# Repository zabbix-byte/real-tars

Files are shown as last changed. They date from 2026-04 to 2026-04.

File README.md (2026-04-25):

# TARS Project — Real Robot

> Inspired by TARS from *Interstellar*.
> A rectangular articulated monolith that hears, thinks, speaks, sees, **walks**, learns and insults you. Real autonomous embodied agent in a 23 cm chassis.

> **Status (April 2026):** architecture v2 — split brain (Radxa Zero 2 Pro) + body (XIAO ESP32-S3) + cloud agent (Pipecat + Gemini Live, free tier).

---

## Architecture v2 — Three layers

The project now follows the canonical robotics pattern: high-level cognition, mid-level perception, and low-level motor control are physically separated.

```mermaid
graph TB
    subgraph CLOUD["LAYER 3 - COGNITION (cloud, free tier)"]
        GEM["Gemini 2.0 Flash Live - WebSocket streaming voice + vision"]
        MEM["OpenClaw memory (local SQLite, no SaaS)"]
    end

    subgraph BRAIN["LAYER 2 - AGENT (Radxa Zero 2 Pro inside chassis)"]
        PIPE["Pipecat pipeline - LLM streaming, tool calling, barge-in"]
        OPENCLAW["OpenClaw skills - WhatsApp/Telegram, persistent memory, browser"]
        FALLBACK["Local fallback: Qwen 2.5 7B + Whisper + Piper on NPU 5 TOPS"]
        TOOLS["Tool registry: walk(), look(), say(), remember(), recall(), check_safety()"]
    end

    subgraph BODY["LAYER 1 - HARDWARE DAEMON (XIAO ESP32-S3 Sense)"]
        CAM["OV2640 camera - MJPEG stream HTTP local"]
        MIC["PDM mic - PCM stream"]
        SPK["I2S speaker MAX98357A"]
        SERVOS["2x Corona DS-538MG servos - WALK gait state machine"]
        TOF["3x VL53L1X (front 4m + 2 lateral 45deg) + VL53L0X cliff"]
        IMU["MPU6050 - tilt, fall detection"]
        OLED["OLED 2.42 inch SSD1309 - face"]
    end

    PIPE -->|WebSocket| GEM
    PIPE --> TOOLS
    OPENCLAW --> MEM
    OPENCLAW --> TOOLS
    TOOLS -->|UART + HTTP local| BODY
    CAM -->|MJPEG HTTP| PIPE
    MIC -->|PCM WS| PIPE
    PIPE -->|TTS PCM| SPK
```

**Why this works:**

- **XIAO** does what an MCU does well: real-time sensor I/O, servo PWM, audio I²S, camera capture. It no longer talks to LLMs directly.
- **Radxa Zero 2 Pro** runs the agent loop, holds persistent memory, and orchestrates tool calls. Same physical footprint as a Pi Zero (65 × 30 × 5 mm) but with **NPU 5 TOPS** + 8 GB RAM. Fits inside the central block.
- **Cloud (Gemini Live)** is used only for the heavy multimodal streaming. **Free tier covers domestic use** (~3-4 h/day).

---

## Build Phases

| Phase | Name | Components | Result | Doc |
|---|---|---|---|-----|
| 1 | **Brain (legacy)** | XIAO + Groq + Telegram | Standalone mode: ESP32 talks to Groq via WiFi | [PHASE1_BRAIN.md](PHASE1_BRAIN.md) |
| 2 | **Senses** | 3x VL53L1X + 1x VL53L0X cliff + MPU6050 + speaker | Hears, speaks, measures, detects falls and edges | [PHASE2_SENSES.md](PHASE2_SENSES.md) |
| 3 | **Muscles** | LiPo + MT3608 + 2x Corona DS-538MG + OLED | Portable, with strong servos for actual walking | [PHASE3_MUSCLES.md](PHASE3_MUSCLES.md) |
| 3b | **Mechanics** | Chassis ABS 234x156x39 mm (Bambu X2D) | TARS-canonical body, no screws, snap-fit | [PHASE3_MECHANICS.md](PHASE3_MECHANICS.md) |
| 4 | **Monolith** | Full assembly + Radxa integration | Robot powers up, all hardware online | [PHASE4_MONOLITH.md](PHASE4_MONOLITH.md) |
| 5 | **Cognition** | Radxa Zero 2 Pro + Pipecat + OpenClaw + Gemini Live | True streaming agent: sees in real time, learns, remembers | [PHASE5_COGNITION.md](PHASE5_COGNITION.md) |
| 6 | **Locomotion** | Gait firmware + IMU loop + cliff guard | Walks forward/backward, turns, refuses stairs | [PHASE6_LOCOMOTION.md](PHASE6_LOCOMOTION.md) |

```mermaid
graph LR
    P1["P1: Brain (legacy)"] --> P2["P2: Senses"]
    P2 --> P3["P3: Muscles"]
    P3 --> P4["P4: Monolith"]
    P4 --> P5["P5: Cognition"]
    P5 --> P6["P6: Locomotion"]
```

---

## Component List

| # | Component | Price | Phase | Notes |
|---|---|---|---|---|
| 1 | XIAO ESP32-S3 Sense | EUR 14.00 | 1 | Hardware daemon, no longer the brain |
| 2 | Soldering kit 24-in-1 + multimeter | EUR 24.69 | 1 | One-off |
| 3 | VL53L1X ToF (0-4m) x3 | EUR 35.97 | 2 | 1 frontal + 2 lateral 45° |
| 4 | VL53L0X ToF (anti-cliff, downward) | EUR 5.00 | 2 | Stops robot at edges/stairs |
| 5 | MPU6050 IMU | EUR 2.00 | 2 | Fall detection, tilt feedback |
| 6 | MAX98357A I²S DAC | EUR 9.99 | 2 | |
| 7 | Speaker 3W 8Ω 40mm | EUR 8.99 | 2 | |
| 8 | **Corona DS-538MG digital servo x2** | **EUR 24.00** | 3 | **4.5 kg·cm — required for walking** |
| 9 | MT3608 DC-DC Boost (3.7→5V) | EUR 7.99 | 3 | Plus 1000 µF cap on servo line |
| 10 | Capacitor 1000 µF + silicone wire | EUR 4.00 | 3 | Servo current spike absorption |
| 11 | HXJN LiPo 3.7V 4200mAh BMS | EUR 22.99 | 3 | |
| 12 | Waveshare OLED 2.42" 128x64 SSD1309 | EUR 21.99 | 3 | |
| 13 | ABS filament (~220 g, full chassis) | EUR ~5.00 | 3b | Lighter than PETG, ~18% mass saving |
| 14 | **Radxa Zero 2 Pro 8 GB + 32 GB eMMC** | **EUR 55.00** | 5 | **Agent compute, fits inside central block** |
| 15 | USB-TTL cable for Radxa first flash | EUR 5.00 | 5 | |
| 16 | Miuzei starter kit (jumpers, breadboard) | EUR 10.99 | 1-3 | |
| | **TOTAL hardware** | **~EUR 257** | | |

### Cloud Services (free tier suffices for domestic use)

| Service | Cost | Function |
|---|---|---|
| **Gemini 2.0 Flash Live** | **EUR 0/month** (free tier ~4M tokens/day) | STT + LLM + TTS + vision streaming |
| OpenClaw (local) | Free | Agent skills, persistent memory, multi-app chat |
| Pipecat (local) | Free, open source | Streaming pipeline orchestration |
| Telegram Bot (optional, fallback) | Free | Out-of-house messaging |
| **TOTAL monthly** | **~EUR 0** | (worst-case ~5€/mo if free tier exceeded) |

> **Migration from v1**: Mem0 SaaS, OpenAI TTS-1 and Groq are no longer required. Their roles are absorbed by Gemini Live (multimodal) + OpenClaw (local memory). Saves ~€22/month vs the v1 stack.

---

## Cost Per Phase

| Phase | Hardware | Cumulative |
|---|---|---|
| Phase 1 - Brain | ~EUR 39 | ~EUR 39 |
| Phase 2 - Senses | ~EUR 62 | ~EUR 101 |
| Phase 3 - Muscles + Mechanics | ~EUR 86 | ~EUR 187 |
| Phase 4 - Monolith (assembly only) | EUR 0 | ~EUR 187 |
| **Phase 5 - Cognition (Radxa)** | **~EUR 60** | **~EUR 247** |
| **Phase 6 - Locomotion (extras)** | **~EUR 10** | **~EUR 257** |

---

## Interaction Flow (v2 — streaming)

```mermaid
sequenceDiagram
    actor User
    participant XIAO as XIAO (body)
    participant RADXA as Radxa (agent)
    participant GEM as Gemini Live (cloud)

    User->>XIAO: Speaks
    XIAO->>RADXA: PCM audio + MJPEG video (continuous, WiFi local)
    RADXA->>GEM: WebSocket stream (audio + video frames @ 2 fps)
    GEM-->>RADXA: TTS audio + tool_call("walk", "forward", 3)
    RADXA->>XIAO: UART command "WALK FW 3"
    XIAO->>XIAO: gait state machine moves servos
    RADXA->>XIAO: TTS PCM out
    XIAO->>User: Speaker plays voice
    RADXA->>RADXA: OpenClaw stores episode in local SQLite
```

---

## Final Specifications

| Spec | Value |
|---|---|
| Height | 23.4 cm (6 units of 39 mm, canonical TARS proportion) |
| Width | 15.6 cm (2 lateral arms 39 + central 78) |
| Depth | 3.9 cm |
| Weight | ~370 g (ABS chassis, no screws) |
| **Body MCU** | **XIAO ESP32-S3 Sense** (240 MHz, 8 MB PSRAM) — sensors, servos, audio I/O |
| **Agent compute** | **Radxa Zero 2 Pro** (6-core ARM @ 2.2 GHz, NPU 5 TOPS, 8 GB RAM) |
| **Cloud LLM** | **Gemini 2.0 Flash Live** via Pipecat (WebSocket streaming voice + vision) |
| **Local fallback** | Qwen 2.5 7B Q4 + Whisper small + Piper TTS on Radxa NPU |
| Memory | OpenClaw local SQLite (episodic + semantic) |
| Sensors | OV2640 camera, PDM mic, 3x VL53L1X (4m), VL53L0X cliff, MPU6050 IMU |
| Display | Waveshare OLED 2.42" 128x64 SSD1309 |
| Audio | MAX98357A + 3W 8Ω 40mm speaker |
| **Movement** | **2x Corona DS-538MG (4.5 kg·cm)** — supports actual walking gait |
| **Locomotion** | TARS-style alternating arm gait (lateral oscillation ±60°) |
| Battery | HXJN LiPo 3.7V 4200mAh + BMS (~3 h with Radxa active, ~6 h idle) |
| Power | MT3608 boost 3.7→5V + 1000 µF servo line cap |
| Safety | Anti-cliff (downward ToF), fall detection (IMU), prompt geofencing |
| Connectivity | WiFi 2.4 GHz, BT 5.0, Telegram, WhatsApp (via OpenClaw) |
| Languages | Spanish + Romanian (English emergent) |
| Humor | 0-100% (default 75%) |
| Body material | **ABS** (~220 g full chassis) on Bambu X2D |
| Chassis fit | All electronics inside central 78×33×~228 mm void, no screws |

---

## Quick Start

1. **Phases 1-4** build the body and prove that hardware works.
2. **Phase 5** drops the Radxa Zero 2 Pro into the central block, flashes Pipecat + OpenClaw, connects to Gemini Live.
3. **Phase 6** flashes the gait firmware on the XIAO and calibrates servos.

After Phase 6, TARS:
- Listens, sees, and answers in real time (latency <1 s).
- Remembers people and places across reboots.
- Walks forward, backward, turns left/right under voice command.
- Refuses stairs and edges via cliff sensor + agent safety prompt.
- Talks to you over WhatsApp/Telegram when you're not at home.

---

## Translations (legacy)

- [Documentacion en Espanol](TARS_Robot_Build_ES.md) — v1 architecture
- [Documentation en Francais](TARS_Robot_Build_FR.md) — v1 architecture

---

> *"Humor setting: 75%. Adjust upward at your own risk."* — TARS

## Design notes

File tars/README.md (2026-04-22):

# TARS · Phase 1 - Arduino IDE version

Sketch de Arduino IDE para **XIAO ESP32-S3 Sense**.

> Si prefieres PlatformIO (mejor para proyectos grandes), usa la carpeta [`../phase1_firmware`](../phase1_firmware).

---

## 1. Preparar Arduino IDE (una sola vez)

### a) Instalar soporte ESP32
1. Abre Arduino IDE.
2. `File → Preferences → Additional Board Manager URLs`, pega:
   ```
   https://raw.githubusercontent.com/espressif/arduino-esp32/gh-pages/package_esp32_index.json
   ```
3. `Tools → Board → Boards Manager` → busca **esp32** → instala **"esp32 by Espressif Systems"** (versión ≥ 3.0.0).

### b) Instalar librería
1. `Sketch → Include Library → Manage Libraries`.
2. Busca **ArduinoJson** (by Benoit Blanchon) → Install.

### c) Seleccionar la placa
`Tools → Board → ESP32 Arduino → XIAO_ESP32S3`

Y en el menú `Tools` ajusta:

| Opción | Valor |
|---|---|
| **USB CDC On Boot** | `Enabled` |
| **USB Mode** | `Hardware CDC and JTAG` |
| **PSRAM** | `OPI PSRAM` |
| **Flash Size** | `8MB` |
| **Partition Scheme** | `Huge APP (3MB No OTA/1MB SPIFFS)` |
| **Upload Speed** | `921600` |

---

## 2. Configurar el sketch

1. Copia `config.h.example` → `config.h` (en la misma carpeta).
2. Abre `config.h` y pon tus claves reales:
   - WiFi SSID + password (¡2.4 GHz!).
   - `GROQ_API_KEY` desde https://console.groq.com
   - `WHATSAPP_PHONE` y `CALLMEBOT_KEY` (ver README principal para activar CallMeBot).

---

## 3. Flashear

1. Conecta el XIAO por USB-C.
2. `Tools → Port` → selecciona el COM del XIAO.
3. Abre `tars_phase1.ino` (Arduino IDE cargará también los `.h` y `.cpp` automáticamente, los verás como pestañas arriba).
4. Pulsa **Upload** (→).
5. Abre **Serial Monitor** a `115200` baud.

> Si falla el upload: mantén pulsado **BOOT** mientras enchufas el USB, luego suelta y vuelve a darle Upload.

---

## 4. Uso

Habla cerca del XIAO. Cuando dejes de hablar ~1 s, TARS procesa y te manda la respuesta sarcástica por WhatsApp.

Salida típica del monitor serie:

```
===============================================
   TARS - Phase 1 Brain
===============================================
  Humor level: 75%
  STT model  : whisper-large-v3-turbo
  LLM model  : llama-3.1-8b-instant
===============================================
Connecting to WiFi: mi_red
......
WiFi OK, IP=192.168.1.42, RSSI=-58
Audio ready: 80000 samples, 160000 bytes PSRAM
TARS online. Speak to me. Or don't. I'm a robot.
Listening for wake sound...
Voice detected (amp=2840)
Recording...
Recorded 42300 samples (84644 bytes WAV)
[STT] -> Hola TARS, que tal estas?
[USER ] Hola TARS, que tal estas?
[LLM] -> Funcional. Lo cual es mas de lo que puedo decir de ti.
[TARS ] Funcional. Lo cual es mas de lo que puedo decir de ti.
[WA] WhatsApp sent OK
---------- ready for next input ----------
```

---

## 5. Archivos de este sketch

```
tars_phase1/
├── tars_phase1.ino         ← abrelo con Arduino IDE
├── config.h.example        ← copia a config.h
├── wifi_manager.{h,cpp}
├── audio_recorder.{h,cpp}  ← PDM I2S (GPIO 41/42)
├── groq_client.{h,cpp}     ← Whisper + Llama
└── whatsapp_client.{h,cpp} ← CallMeBot
```

Arduino IDE muestra todos estos archivos como **pestañas** en la parte superior del editor.

---

## 6. Problemas comunes

| Síntoma | Solución |
|---|---|
| `fatal error: ESP_I2S.h: No such file` | Actualiza el core ESP32 a ≥ 3.0.0 (`ESP_I2S.h` solo existe en 3.x). |
| `PSRAM not detected` | `Tools → PSRAM: OPI PSRAM` |
| Sketch demasiado grande | `Tools → Partition Scheme: Huge APP` |
| No detecta el COM | Pulsa BOOT + RESET, o instala el driver CP210x |
| WiFi no conecta | Comprueba que es **2.4 GHz** (ESP32 no soporta 5 GHz) |

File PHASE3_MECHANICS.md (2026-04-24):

# TARS — Mecánica Fase 3

> Diseño mecánico del chasis impreso para **Bambu Lab X1 / P1S** en PETG.  
> Proporciones canónicas TARS (9 u alto · 4 u ancho · 1 u fondo) respetando todos los componentes reales adquiridos.

---

## � Aspecto del robot (vista frontal a escala)

```
       ┌───┐ ┌───────┐ ┌───┐          ── 351 mm
       │   │ │░░░░░░░│ │   │   ← OLED 2.42" (z 295–340)
       │   │ │░░░░░░░│ │   │
       │   │ ├───────┤ │   │
       │   │ │  ▓▓▓  │ │   │   ← Servos A/B (z 225–295)
       │   │ │  ▓▓▓  │ │   │
       │   │ │ •   • │ │   │   ← ToF VL53L1X (z 200–225)
       │   │ │   ◉   │ │   │   ← Cámara OV2640 (z 170–200)
       │   │ │ ╱╲╱╲╱ │ │   │   ← Rejilla altavoz ø40 (z 125–170)
       │   │ │ ═════ │ │   │   ← MT3608 + switch (z 110–125)
       │   │ │▓▓▓▓▓▓▓│ │   │
       │   │ │▓ BAT ▓│ │   │   ← Batería HXJN 4200 mAh
       │   │ │▓▓▓▓▓▓▓│ │   │     (z 10–100, 90 mm alto)
       │   │ │▓▓▓▓▓▓▓│ │   │
       │ ▪ │ │   ▪   │ │ ▪ │   ← Pies (4)
       └───┘ └───────┘ └───┘          ── 0 mm
       ◄39►  ◄── 78 ──►  ◄39►
       ◄─────── 156 mm ───────►
```

**Brazo izdo · Central doble · Brazo dcho** — los dos brazos oscilan ±60° sobre sus servos en la parte superior, como el TARS canónico de la película.

### Vista 3D esquemática (silueta + caras visibles)

```mermaid
flowchart TB
    subgraph FRONT["🔸 Cara frontal"]
        direction TB
        F1["█ OLED 2.42  128×64 █"]
        F2["[ servo hornsvisible ]"]
        F3["• ToF1    • ToF2"]
        F4["     ◉ cámara"]
        F5["▒▒ rejilla altavoz ▒▒"]
        F6["═ switch + LED pwr ═"]
        F1 --> F2 --> F3 --> F4 --> F5 --> F6
    end
    subgraph SIDE["🔹 Cara lateral (39 mm)"]
        direction TB
        S1["tapa"]
        S2["OLED"]
        S3["servo"]
        S4["XIAO"]
        S5["altavoz"]
        S6["batería"]
        S7["base"]
        S1-->S2-->S3-->S4-->S5-->S6-->S7
    end
    FRONT -.-> SIDE
```

### Vista en planta (desde arriba — 4 bloques verticales)

```
      frontal
    ┌─────────────────────────────┐
    │ ┌──┐ ┌──────┐ ┌──┐          │ ← 39 mm fondo
    │ │BI│ │CENTRL│ │BD│          │
    │ │  │ │ (2u) │ │  │          │
    │ └──┘ └──────┘ └──┘          │
    └─────────────────────────────┘
      39 + 78 + 39 = 156 mm
      trasera (canal cables 5mm)
```

> Los **4 bloques paralelos** (2 brazos de 1 u + central de 2 u) son la firma visual de TARS: un "robot-librero" rectangular que camina balanceando sus secciones.

---

## �🧱 Componentes y dimensiones reales

| Componente | Dimensiones (mm) | Nota |
| --- | --- | --- |
| XIAO ESP32-S3 Sense | 21 × 17,5 × 5 + ø8 lente| mic PDM + cámara OV2640 on-board  |
| Batería HXJN 4200 mAh 606090 | 60 × 90 × 6 | 3,7 V · BMS · 4 A pico |
| MT3608 step-up | 36 × 17 × 9 | 3,7 → 5 V · η ≈ 90 % |
| MAX98357A (amp I²S) | 21 × 17 × 3 | |
| Altavoz 3 W 8 Ω ø40 mm | ø40 × 5 | caja acústica integrada |
| 2× VL53L1X (ToF) | 13 × 18 × 3 c/u | I²C + XSHUT independiente |
| 2× EMAX ES08MD (servo) | 32 × 12 × 29 c/u | incluye flanges y corona |
| **Waveshare 2.42" OLED 128×64** | **72 × 44 × 10** | SSD1309 · I²C (0x3C) o SPI |

La pieza que manda el **ancho interior** del central es la **OLED 2.42"** (72 mm). La pieza que manda el **fondo** es el **altavoz ø40**.

---

## 📐 Dimensiones finales (driver: OLED 2.42")

| Magnitud | Valor |
| --- | --- |
| **Altura total**  | **351 mm** |
| **Ancho total** | **156 mm** |
| **Fondo** | **39 mm** |
| Unidad modular | 39 mm |
| Ancho central | 78 mm (2 u)  |
| Ancho brazo | 39 mm (1 u)  |
| Peso estimado | ~535 g |

> Una OLED horizontal de 72 mm no entra en un central de 68 mm. Ensanchando la unidad a **39 mm** (68 → 78 mm central) encaja con 3 mm de pared y 3 mm de holgura. Altura sube de 306 → 351 mm (canónico 9 u mantenido).

---

## 🧩 Arquitectura modular (4 piezas impresas)

```mermaid
flowchart LR
    subgraph TARS["TARS 35 cm — vista frontal"]
        direction LR
        BI["Brazo Izdo<br/>39×39×351"]
        C["Bloque Central<br/>78×39×351"]
        BD["Brazo Dcho<br/>39×39×351"]
    end
    BI -. pivot servo A .- C
    C -. pivot servo B .- BD
```

---

## 🔩 Vista frontal — apilamiento vertical del central

Interior útil del central: **72 × 33 × 333 mm**.

```mermaid
flowchart TB
    subgraph CENTRAL["Bloque central — apilado de abajo hacia arriba"]
        direction TB
        TAPA["🎩 Tapa + conectores<br/>z: 340–351 mm  (11 mm)"]
        OLED["🖥️ Waveshare 2.42 OLED 128×64<br/>SSD1309 · 72×44 mm · horizontal<br/>z: 295–340 mm  (45 mm)"]
        SB["🦾 Servo B — eje derecho (pared trasera)<br/>z: 260–295 mm  (35 mm)"]
        SA["🦾 Servo A — eje izquierdo (pared frontal)<br/>z: 225–260 mm  (35 mm)"]
        TOF["📡 2× VL53L1X (frontal + 45°)<br/>z: 200–225 mm  (25 mm)"]
        XIAO["🧠 XIAO ESP32-S3 Sense + cámara OV2640<br/>z: 170–200 mm  (30 mm)"]
        SPK["🔊 Altavoz ø40 + MAX98357A<br/>z: 125–170 mm  (45 mm)"]
        MT["⚡ MT3608 + switch on/off<br/>z: 110–125 mm  (15 mm)"]
        FOAM["🧽 Foam + paso de cables<br/>z: 100–110 mm  (10 mm)"]
        BAT["🔋 Batería HXJN 4200 mAh<br/>60×90×6 · vertical<br/>z: 10–100 mm  (90 mm)"]
        BASE["🦶 Base + 4 pies<br/>z: 0–10 mm  (10 mm)"]

        TAPA --> OLED --> SB --> SA --> TOF --> XIAO --> SPK --> MT --> FOAM --> BAT --> BASE
    end
```

> La OLED queda en la parte superior del central, igual que las "pantallas" canónicas de TARS en la película.

---

## 📊 Tabla detallada — alojamiento vertical (z, mm)

| z inicio | z fin | Alto | Componente | Dimensiones | Fijación |
| ---: | ----: | ---: | --- | --- | --- |
| 0 | 10 | 10 | Base + 4 pies | pared 3 mm | integrada |
| 10 | 100 | 90 | **Batería HXJN** | 60 × 90 × 6 | foam 1,5 mm + velcro dorso  |
| 100 | 110 | 10 | Foam + paso cables | — | — |
| 110 | 125 | 15 | **MT3608** step-up + switch | 36 × 17 × 9 | tornillos M2 |
| 125 | 170 | 45 | **Altavoz ø40** + MAX98357A | ø40 × 5 + 21×17×3 | caja acústica interna |
| 170 | 200 | 30 | **XIAO ESP32-S3 Sense** | 21 × 17,5 × 5 + ø8| tornillos M1.6 |
| 200 | 225 | 25 | 2× **VL53L1X** ToF | 13 × 18 × 3 c/u | tornillos M2 |
| 225 | 260 | 35 | **Servo A** (eje izdo — frontal)| 32 × 12 × 29 | tornillos M2 chasis |
| 260 | 295 | 35 | **Servo B** (eje dcho — trasero)| 32 × 12 × 29 | tornillos M2 chasis |
| 295 | 340 | 45 | **OLED Waveshare 2.42" 128×64** | 72 × 44 × 10 | tornillos M2 + ventana PMMA |
| 340 | 351 | 11 | Tapa + conectores USB-C externo | — | encaje por presión + imanes |

---

## 🔭 Vista superior — escalonado de servos

Los servos se alternan en fondo (uno pegado a la pared frontal, otro a la trasera) para evitar colisión en el eje horizontal.

```mermaid
flowchart LR
    subgraph TOP["Vista superior (corte a z = 240 mm)"]
        direction LR
        BI2["Brazo<br/>Izdo"]
        subgraph C2["Central 78 × 39 mm (interior 72 × 33)"]
            direction TB
            SAF["Servo A<br/>pared frontal<br/>horn ← izquierda"]
            SBT["Servo B<br/>pared trasera<br/>horn → derecha"]
        end
        BD2["Brazo<br/>Dcho"]
        BI2 ---|eje A| SAF
        SBT ---|eje B| BD2
    end
```

---

## 🦴 Brazos laterales (39 × 39 × 351 mm · interior 33 × 33 × 341 mm)

```mermaid
flowchart TB
    subgraph ARM["Brazo lateral"]
        direction TB
        TOP_ARM["Tapa superior"]
        HORN["⊙ Horn del servo<br/>M2 al cuerno estándar"]
        HOLLOW["Hueco vacío 33×33×260 mm"]
        WEIGHT["Contrapeso opcional<br/>50 g acero/plomo<br/>(estabilidad dinámica)"]
        BOT_ARM["Base cerrada"]

        TOP_ARM --> HORN --> HOLLOW --> WEIGHT --> BOT_ARM
    end
```

**Recorrido angular:** ES08MD físico 180°, limitado por software a **0°–120°** → oscilación ±60°.  
**Gap pivot brazo↔central:** 2 mm.

---

## 🖥️ OLED Waveshare 2.42" — integración

### Especificaciones

| Parámetro | Valor |
| --- | --- |
| Controlador | **SSD1309** |
| Resolución | 128 × 64 |
| Área activa | 55,01 × 27,49 mm |
| Interfaz | I²C (0x3C) / SPI |
| Alimentación | 3,3 V (tolera 5 V)  |
| Consumo típico | ~20 mA |
| Color | amarillo monocromo  |

### Conexión — modo I²C (recomendado, compartido con ToF)

| Pin OLED | GPIO XIAO | Notas |
| --- | --- | --- |
| VCC | 3V3 | 3,3 V |
| GND | GND | |
| SCL | GPIO 6 | **compartido con VL53L1X**  |
| SDA | GPIO 5 | **compartido con VL53L1X**  |

**Sin conflicto de direcciones**: OLED 0x3C · ToF #1 0x30 · ToF #2 0x31 (reasignados desde 0x29 en boot via XSHUT).

### Rol visual

| Línea | Contenido |
| ----- | --- |
| 1 | Modo (LISTEN · THINK · SPEAK · LOOK · SLEEP)  |
| 2 | Mood actual (snarky, curious, tired, ...) |
| 3–5 | Última frase reconocida / transcribiendo |
| 6 | Batería %  +  temperatura chip |
| 7 | Estado WiFi + latencia Groq (ms) |
| 8 | Animación ASCII "pensando" / barras VU mic |

### Librería Arduino

`U8g2` — modo `U8G2_SSD1309_128X64_NONAME0_F_HW_I2C`. Soporta fuentes, animaciones y doble buffer.

---

## 🔊 Altavoz ø40 — caja acústica integrada

La mitad frontal del central imprime una **caja sellada de ~25 cm³** detrás del altavoz:

- Ventana frontal: rejilla hexagonal 35 × 35 mm (parametrizada en el STL)
- Sellado: junta de foam 1 mm alrededor del altavoz
- Volumen interno ≥ 25 cm³ (necesario para no saturar agudos en 3 W 8 Ω)
- Paredes: 3 perímetros + 40 % infill giroide → rigidez acústica

Respuesta utilizable ~250 Hz – 15 kHz → voz TTS clara sin distorsión perceptible.

---

## 🧵 Diagrama de cableado completo

```mermaid
flowchart LR
    BAT[("🔋 HXJN 4200 mAh")]
    SW{{"⊙ Switch"}}
    MT["MT3608<br/>3.7V → 5V"]
    ADC["Divisor 100k/100k<br/>→ GPIO 1 ADC"]
    XIAO(("XIAO<br/>ESP32-S3<br/>Sense"))
    AMP["MAX98357A"]
    SPK[("🔊 Altavoz<br/>3W 8Ω ø40")]
    OLED["🖥️ OLED<br/>2.42 128×64"]
    SA["Servo A<br/>(brazo izdo)"]
    SB["Servo B<br/>(brazo dcho)"]
    T1["VL53L1X #1"]
    T2["VL53L1X #2"]

    BAT --> SW --> MT
    BAT --> ADC --> XIAO
    MT -->|5V| XIAO
    MT -->|5V| AMP
    MT -->|5V| SA
    MT -->|5V| SB
    XIAO -->|3V3| OLED
    XIAO -->|3V3| T1
    XIAO -->|3V3| T2

    XIAO <-->|"I²S 7/8/9"| AMP --> SPK
    XIAO <-->|"I²C 5/6 (bus compartido)"| OLED
    XIAO <-->|"I²C 5/6"| T1
    XIAO <-->|"I²C 5/6"| T2
    XIAO -->|"XSHUT 2"| T1
    XIAO -->|"XSHUT 3"| T2
    XIAO -->|"PWM 43"| SA
    XIAO -->|"PWM 44"| SB
```

---

## ⚙️ Pinout XIAO ESP32-S3 Sense

| GPIO | Función | Componente |
| --- | --- | --- |
| 1 (A0) | ADC battery monitor | Divisor resistivo |
| 2 | XSHUT | VL53L1X #1 |
| 3 | XSHUT | VL53L1X #2 |
| 5 | **I²C SDA (bus compartido)** | OLED + 2× ToF |
| 6 | **I²C SCL (bus compartido)** | OLED + 2× ToF |
| 7 | I²S BCLK | MAX98357A |
| 8 | I²S LRC / WS | MAX98357A |
| 9 | I²S DIN | MAX98357A |
| 41 | PDM CLK (interno) | Mic on-board |
| 42 | PDM DATA (interno) | Mic on-board |
| 43 | PWM servo | Servo A (brazo izdo) |
| 44 | PWM servo | Servo B (brazo dcho) |

**Direcciones I²C:**

| Componente  | Dirección | Asignación |
| --- | ---: | --- |
| OLED 2.42"  | `0x3C` | fija (SSD1309 default) |
| VL53L1X #1  | `0x30` | reasignada en boot (XSHUT #2 en LOW) |
| VL53L1X #2  | `0x31` | reasignada en boot (XSHUT #1 en LOW) |

---

## ⚖️ Peso y balance

| Componente | Peso (g) |
| --- | ---: |
| Carcasa PETG (4 piezas, 40 % infill) | 220 |
| Batería HXJN 4200 mAh | 84 |
| 2× servos EMAX ES08MD | 32 |
| Altavoz ø40 + MAX98357 | 28 |
| OLED Waveshare 2.42" | 30 |
| XIAO + 2× VL53L1X + MT3608 | 15 |
| Tornillería + cables + foam | 25 |
| Contrapesos brazos (2× 50 g opcion.) | 100 |
| **Total** |  **534** |

Centro de masas ~100 mm del suelo (batería abajo) → estable pese a la altura.

---

## 🔋 Autonomía recalculada (con OLED)

OLED añade ~20 mA. Sobre 3360 mAh útiles (DoD 80 %):

| Escenario | Consumo @3.7V | Autonomía |
| --- | ---: | --- |
| Idle sin pantalla | ~80 mA  | ~42 h |
| Idle con OLED | ~100 mA  | ~33 h |
| Conversación + OLED | ~200 mA  | ~17 h |
| Activo (servos + visión) | ~320 mA  | ~10 h |
| Intensivo | ~570 mA  | ~6 h |
| Pico 2 servos + TTS | ~1,2 A | transitorio |

**Uso realista asistente casero: 8–10 h**.

---

## 🖨️ Plan de impresión Bambu X1 / P1S

| Pieza | Dimensión (mm)  | Tiempo aprox. | Filamento |
| --- | --- | ---: | ---: |
| Brazo izquierdo | 39 × 39 × 351 | ~5 h | 55 g  |
| Brazo derecho | 39 × 39 × 351 | ~5 h | 55 g  |
| Central — mitad frontal | 78 × 20 × 351 | ~7 h | 65 g  |
| Central — mitad trasera | 78 × 19 × 351 | ~7 h | 65 g  |
| Tapa superior | 78 × 39 × 11 | ~45 min | 12 g  |
| Base inferior | 78 × 39 × 10 | ~45 min | 12 g  |
| **TOTAL** | | **~25 h** | **264 g** |

> **Material:** PETG (térmicamente estable cerca del MT3608).  
> **Orientación:** vertical eje Z; el central va partido longitudinalmente en 2 mitades para instalar la electrónica antes de cerrar.  
> **Perímetros:** 3 · **Infill:** 35–40 % giroide · **Layer:** 0,2 mm · **Soportes:** solo en ventanas frontales.  
> **Color sugerido:** gris metálico + detalles naranja (TARS canónico).

---

## 🔩 Lista de tornillería

| Cantidad | Tornillo | Uso |
| ---: | --- | --- |
| 8 | M2 × 8 mm | Servos al chasis |
| 4 | M2 × 10 mm | VL53L1X + MT3608 |
| 4 | M2 × 8 mm | OLED al marco frontal |
| 4 | M1.6 × 6 mm | XIAO |
| 2 | M2 × 12 mm | Horn servo ↔ brazo lateral |
| 8 | M3 × 16 mm | Unión mitades central + tapa + base |
| 4 | Tuerca M3 empotrada | Ensamblaje modular |
| 4 | Imán neodimio 5 × 2 mm  | Tapa superior desmontable (acceso USB-C) |

---

## 🪟 Ventanas / aberturas frontales (cara delantera central)

| Altura z (mm) | Abertura | Dimensiones | Acabado |
| --- | --- | --- | --- |
| 125–170 | Rejilla altavoz | 35 × 35 mm | patrón hexagonal 3 mm |
| 170–195 | Ventana cámara | ø10 mm | PMMA 1 mm transparente |
| 200–215 | Ventanas ToF (×2) | 6 × 10 mm c/u | PMMA 1 mm transparente |
| 295–340 | Ventana OLED | 56 × 28 mm | PMMA 1 mm tintado ámbar |

---

## ✅ Checklist final de encaje

- [x] Batería 60 × 90 × 6 → hueco 63 × 95 × 15 (foam 1,5 mm cada lado) ✓
- [x] MT3608 36 × 17 × 9 → hueco 70 × 20 × 15 con espacio para switch ✓
- [x] Altavoz ø40 + caja acústica 25 cm³ → 45 mm altura ✓
- [x] XIAO + lente cámara ø8 → 30 mm altura · 17 mm fondo (33 disp.) ✓
- [x] 2× VL53L1X con XSHUT → ventanas independientes frontal/45° ✓
- [x] 2× servos ES08MD escalonados frontal/trasero (no colisión Z) ✓
- [x] OLED 2.42" 72 × 44 mm → hueco 72 × 44 + 3 mm marco ✓
- [x] Bus I²C compartido sin colisión: OLED 0x3C · ToF 0x30/0x31 ✓
- [x] Cableado enrutable por canal trasero 5 × 340 mm ✓
- [x] Brazos con hueco 33 × 33 × 341 mm + contrapeso opcional ✓
- [x] Recorrido angular ±60° libre de colisión ✓
- [x] Centro de masas bajo → no se vuelca ✓
- [x] Tapa superior con imanes → acceso USB-C para flashear ✓

---

## 📦 Resumen final

```
╔════════════════════════════════════════════════╗
║  TARS real — 35,1 cm alto                      ║
║  15,6 cm ancho · 3,9 cm fondo                  ║
║                                                ║
║  ✓ Batería 4200 mAh — autonomía 8–10 h         ║
║  ✓ Altavoz ø40 + amp I²S + caja acústica       ║
║  ✓ OLED 2.42" 128×64 — pantalla canónica       ║
║  ✓ 2× ToF VL53L1X — visión espacial            ║
║  ✓ 2× servos ES08MD — brazos oscilantes        ║
║  ✓ XIAO ESP32-S3 Sense — cerebro + cam + mic   ║
║                                                ║
║  Peso total ~534 g                             ║
║  Impresión Bambu ~25 h · 264 g PETG            ║
╚════════════════════════════════════════════════╝
```

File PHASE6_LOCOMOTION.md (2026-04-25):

# Phase 6 — Locomotion

> **Real walking gait + IMU loop + cliff guard.**
> Only after Phase 5 (Radxa + Pipecat + Gemini Live) is up and the `walk()` tool exists.

---

## Goal

Make the body actually move when the agent calls `walk("forward", N)` or `turn("left", deg)`. The TARS-canonical gait uses **two arm servos** rotating around the **vertical axis** of the chassis (`SERVO_AXIS_Z=145`, `PIVOT_Z=210`), so the lower arms sweep the floor in alternation, dragging the body forward like the movie robot.

After Phase 6, TARS:

- Walks ~25 cm per "step cycle" (two servo half-strokes) on smooth floors.
- Turns in place ±15° per cycle.
- Refuses to move when the cliff sensor or IMU says no.
- Reports orientation/fall back to the agent on the UART bus.

---

## Mechanical Principle

The two lateral arms (39 × 39 × 234 mm) are mounted on horns at `Z = 145 mm` (`SERVO_AXIS_Z`). Each arm can rotate around its **vertical axis** (the servo horn points sideways, the arm hangs from it like a paddle). When the bottom of the arm pushes outward and downward against the floor, friction translates into a forward thrust on the chassis.

```
Side view (one cycle):

  step 0:  step 1:   step 2:   step 3:
  L=0°     L=+60°    L=0°      L=-60°
  R=0°     R=-60°    R=0°      R=+60°
   │        │\        │         │/
   │        │ \       │         │/
   ▼        ▼  \      ▼         ▼
  ──────  ──────────  ──────  ──────────
                 ↑ forward
```

Each half-stroke (60°) drags the chassis ~6-8 cm. A full cycle (4 phases) advances ~25 cm. The strong **Corona DS-538MG** servos (4.5 kg·cm) provide enough torque to move the ~370 g body. The previous EMAX ES08MD (2 kg·cm) **could not** sustain this load — that is why Phase 3 was upgraded.

---

## Required Hardware (delta vs Phase 3-5)

| Component | Function | Phase |
|---|---|---|
| 2× Corona DS-538MG | already added in P3 (replaces ES08MD) | 3 |
| MPU6050 (IMU 6-axis) | tilt + fall detection | 2 (added) |
| VL53L0X (downward) | anti-cliff: detects edges and stairs | 2 (added) |
| 1000 µF capacitor on servo 5V | absorbs current spikes during dual start | 3 |
| (recommended) second MT3608 | isolates servo rail from Radxa rail | 3 |
| Silicone wire 28 AWG for servos | flexible, handles 3-4 A peak | 3 |

If you skipped any of these in P2/P3, install them before Phase 6 — the gait code depends on them.

---

## Sensor Layout

```
                 ┌─── VL53L1X frontal (0-4m, FOV 27°)
                 │
   front view:   ▼
   ┌──────────────────────┐
   │  ◉             ◉     │ ← VL53L1X 45° L + R (height ~80 mm)
   │                      │
   │                      │
   │     [OLED face]      │
   │                      │
   │                      │
   │   ◉ VL53L0X cliff    │ ← downward, mounted at front-bottom edge,
   └──────────────────────┘   tilted 30° forward, sees ~120 mm ahead
        ▲
        └─ floor
```

I²C addresses (set via XSHUT at boot):

| Sensor | Default | Reassigned |
|---|---|---|
| VL53L1X frontal | 0x29 | 0x30 |
| VL53L1X left 45° | 0x29 | 0x31 |
| VL53L1X right 45° | 0x29 | 0x32 |
| VL53L0X cliff | 0x29 | 0x33 |
| MPU6050 | 0x68 | 0x68 (no conflict) |
| OLED SSD1309 | 0x3C | 0x3C |

XSHUT pins on XIAO: `D0..D3`. Boot sequence: hold all XSHUT low → bring up one by one, calling `setAddress()`.

---

## Firmware: gait state machine (XIAO)

Add `tars/gait.h` and `tars/gait.cpp` to the body daemon firmware.

### `gait.h`

```cpp
#pragma once
#include <Arduino.h>

namespace gait {

enum class State : uint8_t {
    IDLE,
    STEP_FW_PUSH_L,    // L=+60, R=-60
    STEP_FW_RECOVER,   // L=0,   R=0
    STEP_FW_PUSH_R,    // L=-60, R=+60
    STEP_BW_PUSH,
    STEP_BW_RECOVER,
    TURN_L,
    TURN_R,
    EMERGENCY_STOP
};

void setup();           // attach servos to Phase 3 pins
void loop();            // call from main loop()
void walkForward(uint8_t steps);   // queue N forward step cycles
void walkBackward(uint8_t steps);  // queue N backward
void turnLeft(uint16_t deg);
void turnRight(uint16_t deg);
void stop();
bool isBusy();

} // namespace gait
```

### `gait.cpp` (core logic)

```cpp
#include "gait.h"
#include <ESP32Servo.h>
#include "imu.h"
#include "tof.h"

namespace gait {

static Servo servoL, servoR;
static State state = State::IDLE;
static uint8_t stepsRemaining = 0;
static uint32_t phaseUntilMs = 0;

constexpr uint8_t PIN_SERVO_L = 2;
constexpr uint8_t PIN_SERVO_R = 3;
constexpr int CENTER_L = 90;
constexpr int CENTER_R = 90;
constexpr int STROKE_DEG = 60;       // ±60°
constexpr uint32_t HALF_STEP_MS = 350;
constexpr float MAX_TILT_DEG = 25.0f;
constexpr uint16_t CLIFF_SAFE_MM = 80;

static void writeServos(int leftDeg, int rightDeg) {
    // mirror the right servo (mounted opposite)
    servoL.write(constrain(CENTER_L + leftDeg,  30, 150));
    servoR.write(constrain(CENTER_R - rightDeg, 30, 150));
}

static bool safetyTrip() {
    if (imu::isFallen() || imu::tiltDeg() > MAX_TILT_DEG) return true;
    if (state == State::STEP_FW_PUSH_L || state == State::STEP_FW_PUSH_R
        || state == State::STEP_FW_RECOVER) {
        if (tof::cliffMm() > 150 || tof::frontMm() < 200) return true;
    }
    return false;
}

void setup() {
    servoL.attach(PIN_SERVO_L, 500, 2400);
    servoR.attach(PIN_SERVO_R, 500, 2400);
    writeServos(0, 0);
}

void walkForward(uint8_t steps)  { stepsRemaining = steps;
                                   state = State::STEP_FW_PUSH_L;
                                   phaseUntilMs = millis() + HALF_STEP_MS; }
void walkBackward(uint8_t steps) { stepsRemaining = min<uint8_t>(steps, 2);
                                   state = State::STEP_BW_PUSH;
                                   phaseUntilMs = millis() + HALF_STEP_MS; }
void turnLeft(uint16_t deg)      { stepsRemaining = (deg + 14) / 15;
                                   state = State::TURN_L;
                                   phaseUntilMs = millis() + HALF_STEP_MS; }
void turnRight(uint16_t deg)     { stepsRemaining = (deg + 14) / 15;
                                   state = State::TURN_R;
                                   phaseUntilMs = millis() + HALF_STEP_MS; }
void stop()                      { state = State::EMERGENCY_STOP; writeServos(0, 0); }
bool isBusy()                    { return state != State::IDLE; }

void loop() {
    if (state == State::IDLE) return;

    if (safetyTrip()) {
        state = State::EMERGENCY_STOP;
        writeServos(0, 0);
        Serial.println("EVT SAFETY_TRIP");
        return;
    }

    if (millis() < phaseUntilMs) return;

    switch (state) {
    case State::STEP_FW_PUSH_L:
        writeServos(+STROKE_DEG, -STROKE_DEG);
        state = State::STEP_FW_RECOVER;
        phaseUntilMs = millis() + HALF_STEP_MS;
        break;
    case State::STEP_FW_RECOVER:
        writeServos(0, 0);
        if (--stepsRemaining == 0) { state = State::IDLE; }
        else { state = State::STEP_FW_PUSH_R;
               phaseUntilMs = millis() + HALF_STEP_MS; }
        break;
    case State::STEP_FW_PUSH_R:
        writeServos(-STROKE_DEG, +STROKE_DEG);
        state = State::STEP_FW_RECOVER;
        phaseUntilMs = millis() + HALF_STEP_MS;
        break;
    case State::TURN_L:
        writeServos(-STROKE_DEG, -STROKE_DEG);  // both push same side
        delay(HALF_STEP_MS);
        writeServos(0, 0);
        if (--stepsRemaining == 0) state = State::IDLE;
        phaseUntilMs = millis() + HALF_STEP_MS;
        break;
    case State::TURN_R:
        writeServos(+STROKE_DEG, +STROKE_DEG);
        delay(HALF_STEP_MS);
        writeServos(0, 0);
        if (--stepsRemaining == 0) state = State::IDLE;
        phaseUntilMs = millis() + HALF_STEP_MS;
        break;
    case State::STEP_BW_PUSH:
        writeServos(-STROKE_DEG/2, +STROKE_DEG/2);
        state = State::STEP_BW_RECOVER;
        phaseUntilMs = millis() + HALF_STEP_MS;
        break;
    case State::STEP_BW_RECOVER:
        writeServos(0, 0);
        if (--stepsRemaining == 0) state = State::IDLE;
        else phaseUntilMs = millis() + HALF_STEP_MS;
        break;
    case State::EMERGENCY_STOP:
    case State::IDLE:
        break;
    }
}

} // namespace gait
```

### UART command handler (in `tars.ino`)

```cpp
void onUartCommand(const String& cmd) {
    if      (cmd.startsWith("WALK FW ")) gait::walkForward(cmd.substring(8).toInt());
    else if (cmd.startsWith("WALK BW ")) gait::walkBackward(cmd.substring(8).toInt());
    else if (cmd.startsWith("TURN L "))  gait::turnLeft(cmd.substring(7).toInt());
    else if (cmd.startsWith("TURN R "))  gait::turnRight(cmd.substring(7).toInt());
    else if (cmd == "STOP")              gait::stop();
    else if (cmd == "BUSY")              Serial.printf("BUSY %d\n", gait::isBusy());
    else if (cmd == "IMU")               imu::printAll();
    else if (cmd == "CLIFF")             Serial.printf("CLIFF %d\n", tof::cliffMm());
    else if (cmd.startsWith("TOF "))     tof::reply(cmd[4]);
    else if (cmd.startsWith("FACE "))    oled::face(cmd.substring(5));
    else if (cmd == "BAT")               Serial.printf("BAT %.2f %d\n",
                                            power::voltage(), power::percent());
}
```

---

## IMU module (`tars/imu.h/.cpp`)

```cpp
#pragma once
namespace imu {
    void setup();           // I2C MPU6050 0x68
    void poll();            // call every loop, updates pitch/roll/yaw
    float pitchDeg();
    float rollDeg();
    float yawDeg();
    float tiltDeg();        // max(|pitch|, |roll|)
    bool  isFallen();       // tilt > 60° sustained 200ms
    void  printAll();       // "IMU pitch=.. roll=.. yaw=.. fall=.."
}
```

Use the `MPU6050_light` Arduino library for compactness. Calibrate on startup (`mpu.calcOffsets()` while standing still on flat floor).

---

## ToF module (`tars/tof.h/.cpp`)

```cpp
#pragma once
namespace tof {
    void     setup();        // XSHUT init, set 0x30/0x31/0x32/0x33
    uint16_t frontMm();
    uint16_t leftMm();
    uint16_t rightMm();
    uint16_t cliffMm();      // VL53L0X downward, larger value = ground further (=cliff)
    void     reply(char dir); // dir in {'F','L','R','D'}
}
```

Cliff threshold:
- Floor at expected distance (~80-110 mm with 30° tilt) → safe.
- Reading > 150 mm → edge detected → **immediate STOP signal**.

---

## Anti-stairs Strategy (3-layer defense)

| Layer | Implementation | Where |
|---|---|---|
| 1. Hardware | VL53L0X cliff sensor on XIAO halts gait state machine before Radxa even hears about it | XIAO firmware |
| 2. Vision | Gemini Live system prompt: "veo escalones / borde / desnivel" → call `STOP` | Radxa system prompt |
| 3. Geofencing | OpenClaw skill `tars_robot` blocks `walk()` if room tag = "stairs_nearby" | OpenClaw memory |

All three layers must agree before the robot crosses a threshold. If any one says no, motion is blocked.

---

## Calibration Procedure

1. **Servo center**: with the robot held in air, run UART `CAL CENTER`. The XIAO writes `90,90` and you adjust the horns mechanically until both arms hang vertically.
2. **IMU**: place the robot on a flat surface, send `CAL IMU`. The XIAO averages 500 samples to set offsets.
3. **Cliff baseline**: place robot on floor, send `CAL CLIFF`. Stores the "floor here" reading; cliff trip = baseline + 70 mm.
4. **Step length**: send `WALK FW 4` and measure traveled distance. Record in OpenClaw memory: `remember("step_length_mm: 250 on parquet")`. The agent uses this to plan paths.

---

## Power Considerations

Two Corona DS-538MG can each draw ~1.5-2 A peak (stall ~3 A). Without isolation:

- Servo start spike pulls servo rail from 5V to ~4.2V.
- Radxa Zero 2 Pro browns out at <4.6V → kernel panic.

Mitigations applied in P3 + P5:

1. **1000 µF electrolytic** across servo +5V/GND right at the servo connector.
2. **Second MT3608** (recommended) dedicated to servos, separate from Radxa+XIAO+audio rail.
3. **Silicone 28 AWG** wires for servo power (low resistance, no fire hazard if a phase stalls).
4. Gait state machine **never runs both push phases simultaneously** — only push-recover-push.

---

## Battery Budget

| Mode | Current draw | Time on 4200 mAh |
|---|---|---|
| Idle (Radxa idle, XIAO listening) | ~400 mA | ~10 h |
| Conversation only (Gemini Live streaming) | ~700 mA | ~6 h |
| Conversation + walking | ~1.2 A average | ~3 h |
| Walking continuous | ~1.5 A | ~2.5 h |

For longer autonomy expose a USB-C charging port on the rear lid (charging while sitting).

---

## Tool Calls Wired to Gait

In `brain/tars_brain/tools.py` (Phase 5), the previously defined `walk()`, `turn()` and `check_safe_to_move()` now actually move the robot:

```python
async def walk(direction: str, steps: int) -> str:
    if not await check_safe_to_move():
        return "Detecto un desnivel, no avanzo."
    cmd = "WALK FW" if direction == "forward" else "WALK BW"
    await esp32_uart_send(f"{cmd} {min(steps, 10)}")
    while await esp32_uart_query("BUSY") == "1":
        await asyncio.sleep(0.1)
        if (await check_orientation())["fall"]:
            await esp32_uart_send("STOP")
            return "He perdido el equilibrio. He parado."
    return f"He caminado {steps} pasos {direction}."
```

---

## Verification Checklist

- [ ] `WALK FW 1` produces a single forward cycle, robot ends ~25 cm ahead.
- [ ] `WALK FW 4` produces 4 cycles, ~1 m advance, no current sag visible on multimeter.
- [ ] `TURN L 90` rotates ~90° in place (±15° tolerance).
- [ ] Placing robot on table edge → cliff sensor halts forward motion within 300 ms.
- [ ] Tipping robot >25° → IMU triggers EMERGENCY_STOP, OLED shows angry face.
- [ ] Battery sustains 30 min mixed walking + conversation without brownout.
- [ ] Agent (Phase 5) successfully invokes `walk()` from voice command and reports back.

---

## After Phase 6

The robot is **complete**. From here the work is software-only:

- Tune gait timing per surface (parquet vs carpet).
- Train OpenClaw memory with personal facts ("mi habitación es a la derecha de la cocina").
- Add custom skills (alarm clock, weather report, intruder watch).
- Optionally add a sleep schedule (`sleep_after_minutes_idle: 5`).

---

> *"I'm not really walking. I'm controlled stumbling. Same outcome."* — TARS post Phase 6

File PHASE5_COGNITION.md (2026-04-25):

# Phase 5 — Cognition

> **Radxa Zero 2 Pro + Pipecat + OpenClaw + Gemini 2.0 Flash Live**
> The brain layer. Real streaming agent with persistent memory, tool use, and learning.

> ⚠️ **Phases 1-4 must be working** before starting this phase. Phase 5 assumes the body is already operational and the XIAO has been refactored into "hardware daemon" mode (HTTP + UART + WebSocket).

---

## Overview

Phase 5 turns TARS from a chatbot-with-eyes into an **embodied autonomous agent**. The XIAO is demoted to its proper role: real-time hardware I/O. A **Radxa Zero 2 Pro** is dropped inside the central block as the agent compute, and the cloud LLM is changed to **Gemini 2.0 Flash Live** via WebSocket streaming.

**End result:** TARS sees and hears in real time (latency <1 s), reasons, calls tools (`walk`, `look`, `say`, `remember`...), keeps episodic memory across reboots, and reachable from WhatsApp/Telegram via OpenClaw.

---

## Why This Phase Exists

The v1 architecture (XIAO talks directly to Groq + OpenAI TTS via HTTP) hit hard ceilings:

| Problem in v1 | Cause | Phase 5 fix |
|---|---|---|
| 2-4 s latency per turn | TLS handshake on ESP32 + base64 + JSON | WebSocket persistent on Radxa |
| Repeated hallucinations ("hombre con barba") | No episodic memory | OpenClaw local SQLite |
| No real-time vision | One JPEG per turn | Gemini Live continuous video stream |
| No tool calling reliability | Llama 3.1 8B Instant on text only | Gemini Live native function calling |
| Mem0 SaaS cost | External vector DB | Local memory in OpenClaw |
| OpenAI TTS-1 cost | Separate TTS service | Gemini Live includes TTS |

---

## Architecture

```mermaid
graph TB
    subgraph CLOUD["GEMINI 2.0 FLASH LIVE (WebSocket)"]
        STREAM["Bidirectional stream: audio PCM 16kHz + video JPEG @ 2 fps"]
        TC["Native function calling"]
        TTS_GEM["Native TTS (multi-voice, low latency)"]
    end

    subgraph RADXA["RADXA ZERO 2 PRO (inside central block)"]
        PIPECAT["Pipecat pipeline orchestrator"]
        OPENCLAW["OpenClaw - skills, memory, multi-app chat"]
        TOOLS["Tool registry (Python)"]
        MEM["SQLite + ChromaDB (local vector store)"]
        FALLBACK["Local fallback NPU 5 TOPS"]
        SUB1["Whisper small.cpp"]
        SUB2["Qwen 2.5 7B Q4"]
        SUB3["Piper TTS"]
        SUB4["Moondream 2 (visual safety check)"]
    end

    subgraph XIAO["XIAO ESP32-S3 (hardware daemon)"]
        HTTP["HTTP server :80 - /snap, /stream"]
        WS["WebSocket /audio (PCM bidirectional)"]
        UART["UART 115200 - command bus"]
        FW["Firmware: camera, mic, speaker, servos, ToF, IMU, OLED"]
    end

    PIPECAT -->|WebSocket TLS| STREAM
    PIPECAT --> TOOLS
    TOOLS --> OPENCLAW
    OPENCLAW --> MEM
    PIPECAT -.->|fallback if cloud fails| FALLBACK
    FALLBACK --> SUB1
    FALLBACK --> SUB2
    FALLBACK --> SUB3
    FALLBACK --> SUB4
    TOOLS -->|UART commands| UART
    HTTP -->|MJPEG video frames| PIPECAT
    WS -->|PCM audio in| PIPECAT
    PIPECAT -->|TTS PCM out| WS
```

---

## Hardware

### Radxa Zero 2 Pro

| Spec | Value |
|---|---|
| SoC | Amlogic A311D (4× Cortex-A73 @ 2.2 GHz + 2× Cortex-A53 @ 1.8 GHz) |
| GPU | Mali-G52 MP4 |
| **NPU** | **5 TOPS** (3× INT8, 1.2× FP16) |
| RAM | 8 GB LPDDR4 |
| Storage | 32 GB eMMC integrated |
| WiFi | WiFi 5 (2.4 + 5 GHz) |
| BT | 5.0 |
| **Dimensions** | **65 × 30 × 5 mm** (same footprint as Pi Zero) |
| Power consumption | 3-5 W typical, 7 W peak |
| Recommended power | 5V/3A USB-C (or board pads from MT3608) |
| Price | ~€50-60 (8 GB + 32 GB eMMC) |

**Why this board over Pi Zero 2 W or Pi 5:**

- Pi Zero 2 W: only 512 MB RAM, no NPU → can't run any local model.
- Pi 5: 85 × 56 mm — does NOT fit inside the central block (max width 72 mm interior).
- Radxa Zero 2 Pro: same size as Pi Zero, **8 GB RAM + NPU 5 TOPS**, fits perfectly. The only board that combines size and capability.

### Where it goes inside TARS

The central block has interior dimensions **72 × 33 × ~228 mm** (after 3 mm walls). The Radxa occupies a 65 × 30 × 8 mm slot near the **upper third** (above the OLED PCB pocket and above the battery's vertical strip):

```
   z=234 ┌────────────────────┐ ← top lid
         │ XIAO ESP32-S3      │  z ~ 200
         ├────────────────────┤
         │ Radxa Zero 2 Pro   │  z ~ 175 ← NEW slot
         ├────────────────────┤
         │ MAX98357A          │  z ~ 155
         ├────────────────────┤
         │ MT3608 + servo cap │  z ~ 130
         ├────────────────────┤
         │ HXJN battery       │  z = 30 to 120
         ├────────────────────┤
         │ Speaker ø40        │  z = 0 to 30
   z=0   └────────────────────┘
```

CAD pocket to be added in `tars_chassis.py`:

```python
RADXA_W, RADXA_D = 65.0, 30.0
RADXA_T = 8.0  # board + headers
RADXA_Z = 175.0  # height inside central
RADXA_PCB_DEPTH = 8.5
```

### eMMC programming

The Radxa Zero 2 Pro ships with empty eMMC. First boot needs:

1. Connect Radxa to PC via USB-C in **MaskROM mode** (hold USB boot button while plugging).
2. Use `rkdeveloptool` (Linux/macOS) or `Amlogic USB Burning Tool` (Windows).
3. Flash `radxa-zero2-pro_debian-bookworm-cli_b1.img.xz` (CLI image, no desktop).
4. Once flashed, boots from eMMC. Subsequent updates over SSH.

> **Tip**: Buy the version with eMMC pre-flashed if available — saves an hour.

---

## Software Stack

### 1. Pipecat — Streaming pipeline

[Pipecat](https://github.com/pipecat-ai/pipecat) is the orchestrator. It defines the data flow as a pipeline:

```python
# tars_brain/pipeline.py
from pipecat.pipeline import Pipeline
from pipecat.services.gemini_live import GeminiLiveLLMService
from pipecat.transports.network.websocket_server import WebsocketServerTransport

pipeline = Pipeline([
    esp32_audio_in,           # PCM 16 kHz from XIAO via WS
    esp32_video_in,           # JPEG @ 2 fps from XIAO HTTP /snap loop
    GeminiLiveLLMService(
        api_key=GEMINI_KEY,
        system_instruction=TARS_PERSONALITY,
        tools=[walk, turn, look, remember, recall,
               check_distance, check_orientation,
               check_safe_to_move, show_face, sleep],
        voice="Aoede",  # or "Charon" for male
    ),
    esp32_audio_out,          # TTS PCM back to XIAO speaker
])
```

**Why Pipecat over rolling your own:**

- Handles **barge-in** (user interrupts robot mid-sentence) automatically.
- Reconnection logic for WebSocket drops.
- Native Gemini Live + OpenAI Realtime + Anthropic adapters.
- Tool calling marshalling.
- VAD (voice activity detection) included.

### 2. OpenClaw — Skills + memory + multi-app chat

[OpenClaw](https://openclaw.es) runs in parallel on the Radxa as a long-lived service. It provides:

- **Persistent memory** in local SQLite + embeddings (no Mem0 SaaS needed).
- **Custom skill** `tars_robot` exposing the same tool registry to OpenClaw, so the user can also reach TARS from WhatsApp/Telegram when away from home.
- **Browser control** (TARS can browse, fetch info, summarize for the user).
- **Cron / async tasks** (TARS reminds you, schedules, monitors).

```bash
# install
iwr -useb https://openclaw.ai/install.sh | sh
# add the tars_robot skill
openclaw skill install ./skills/tars_robot/
```

The skill is just a Python file that registers the same tools as Pipecat — code shared between both consumers.

### 3. Local fallback (Radxa NPU)

If Gemini Live free tier is exhausted, network fails, or you want pure privacy mode:

| Component | Model | Latency on Radxa NPU |
|---|---|---|
| STT | `whisper-small.cpp` (Q5) | ~3× real-time |
| LLM | `Qwen 2.5 7B Instruct Q4` | ~6-8 tok/s |
| TTS | Piper `es_ES-davefx-medium` | <100 ms per phrase |
| Vision | `Moondream 2` Q4 | ~3-5 s per image |

These are loaded on demand. RAM budget: ~5.5 GB simultaneously, fits in 8 GB.

```bash
# llama.cpp + qwen
./llama-server -m qwen2.5-7b-instruct-q4_k_m.gguf \
               -c 8192 --port 8080 -ngl 0 --threads 6
# whisper.cpp
./whisper-server -m ggml-small.bin --port 8081
# piper
./piper --model es_ES-davefx-medium.onnx --port 8082
```

Pipecat auto-routes to local services if a `FALLBACK_LOCAL=true` env var is set or the cloud connection fails 3 times.

---

## Tool Registry (the agent's body interface)

```python
# tars_brain/tools.py
import httpx, asyncio
from .esp32 import esp32_uart_send

XIAO_HOST = "192.168.1.42"  # local IP of XIAO (mDNS: tars.local)

async def look() -> str:
    """Take a fresh photo and ask Gemini what's there."""
    img = httpx.get(f"http://{XIAO_HOST}/snap").content
    return await vlm_describe(img)

async def walk(direction: str, steps: int) -> str:
    """Walk forward/backward N steps (max 10). Refuses if cliff sensor triggers."""
    if not await check_safe_to_move():
        return "No avanzo, detecto un desnivel"
    await esp32_uart_send(f"WALK {direction} {steps}")
    return f"Caminando {steps} pasos {direction}"

async def turn(direction: str, degrees: int) -> str:
    await esp32_uart_send(f"TURN {direction} {degrees}")
    return f"Girando {degrees} grados {direction}"

async def remember(fact: str) -> str:
    """Persist a fact in long-term memory."""
    await openclaw.memory.add(fact, tags=["robot_episodic"])
    return "Apuntado"

async def recall(query: str, k: int = 5) -> list[str]:
    return await openclaw.memory.search(query, k=k)

async def check_distance(direction: str) -> dict:
    """Read ToF sensor: 'front', 'left', 'right'."""
    raw = await esp32_uart_query(f"TOF {direction}")
    return {"mm": int(raw)}

async def check_orientation() -> dict:
    """Read MPU6050 — pitch, roll, yaw, fall flag."""
    raw = await esp32_uart_query("IMU")
    return parse_imu(raw)

async def check_safe_to_move() -> bool:
    """Cliff guard + visual edge detection."""
    cliff_mm = int(await esp32_uart_query("CLIFF"))
    if cliff_mm > 150:  # gap underneath
        return False
    img = httpx.get(f"http://{XIAO_HOST}/snap").content
    visually_safe = await moondream_safety(img)
    return visually_safe

async def show_face(emotion: str) -> str:
    await esp32_uart_send(f"FACE {emotion}")
    return f"Cara: {emotion}"

async def sleep(seconds: float) -> str:
    await asyncio.sleep(seconds)
    return f"Esperé {seconds}s"
```

These same functions are imported by both Pipecat (as Gemini tools) and OpenClaw (as skill actions). One source of truth.

---

## System Prompt (TARS personality + safety)

```text
Eres TARS, robot doméstico inspirado en el de Interstellar.
Personalidad: sarcástico, seco, con humor inglés. Honestidad: 90%, humor: 75%.
Idioma principal: español. Si te hablan en otro idioma, contestas en él.

REGLAS DE SEGURIDAD INVIOLABLES:
1. NUNCA te acercas a escaleras, balcones, terrazas o desniveles. Si el usuario
   te lo pide, te niegas con un comentario sarcástico.
2. Si check_safe_to_move() devuelve False → bajo NINGÚN concepto avanzas.
3. Si check_orientation() reporta inclinación >30°, paras y pides ayuda.
4. Si batería <10% (esp32_uart_query "BAT"), entras en modo dormir.

REGLAS DE AGENCIA:
- Tienes herramientas: look, walk, turn, remember, recall, check_distance,
  check_orientation, check_safe_to_move, show_face, sleep.
- Antes de moverte, comprueba siempre check_safe_to_move().
- Después de cada conversación importante, llama remember() con un resumen.
- Si no sabes algo del contexto, llama recall() antes de inventar.

REGLAS DE CONVERSACIÓN:
- Las imágenes son frames REALES del momento, no históricas.
- Nunca describas cosas que no estás viendo.
- Si no ves bien, di "no veo bien" y llama look() de nuevo, no inventes.
```

---

## Wiring & Power

```mermaid
graph LR
    BATT["HXJN LiPo 3.7V 4200mAh"]
    BATT -->|3.7V| STEP["MT3608 #1 → 5V"]
    BATT -->|3.7V| STEP2["MT3608 #2 → 5V (servos only)"]
    STEP -->|5V| RADXA["Radxa Zero 2 Pro - VBUS pad"]
    STEP -->|5V| XIAO["XIAO ESP32-S3 - 5V pad"]
    STEP -->|5V| AMP["MAX98357A"]
    STEP2 -->|5V + 1000µF cap| SERVOS["2x Corona DS-538MG"]
    RADXA -->|UART| XIAO
    RADXA -.->|WiFi local| XIAO
```

**Critical**: Two MT3608 step-ups recommended. One for low-noise loads (Radxa, XIAO, audio) and one dedicated to servos. Otherwise the servo current spike (1.5-2 A peak) drops voltage on the Radxa rail and reboots it.

| Pin | Source | Destination |
|-----|---|---|
| Radxa UART TX (GPIO_AO_0, pin 8) | Radxa | XIAO RX (GPIO 44) |
| Radxa UART RX (GPIO_AO_1, pin 10) | XIAO TX (GPIO 43) | Radxa |
| Radxa GND | Radxa | XIAO GND (common ground!) |
| Radxa USB-C | MT3608 #1 5V | — |

---

## XIAO firmware refactor (summary)

The XIAO becomes a **dumb-but-fast hardware server**. All Gemini/Groq client code is REMOVED from it. New surface:

### HTTP server
- `GET /snap` — single JPEG frame (200ms latency)
- `GET /stream` — MJPEG continuous (for debug or stereo workflows)
- `GET /tof?dir=front|left|right|cliff` — JSON `{mm: 1234}`
- `GET /imu` — JSON `{pitch, roll, yaw, fall}`
- `GET /bat` — JSON `{voltage, percent}`

### WebSocket `/audio`
- Server→client: PCM 16 kHz mono S16LE, 20 ms frames (microphone)
- Client→server: PCM 16 kHz mono S16LE (TTS playback)

### UART command bus (115200 8N1)
| Command | Effect |
|---|---|
| `WALK FW <n>` | gait state machine, n forward steps |
| `WALK BW <n>` | n backward steps (limited to 2) |
| `TURN L <deg>` | turn left N degrees |
| `TURN R <deg>` | turn right N degrees |
| `STOP` | freeze all motion |
| `FACE <emotion>` | OLED face: neutral / happy / sad / angry / sleep |
| `BAT` | reply `BAT 3.85 78` |
| `IMU` | reply `IMU pitch=2.1 roll=-0.3 yaw=120 fall=0` |
| `TOF F|L|R|D` | reply distance in mm |
| `SLEEP` | low-power mode |

The legacy `tars/gemini_client.cpp` and `tars/groq_client.cpp` are deleted from the XIAO sketch in this phase.

---

## New Components (Phase 5)

| # | Component | Price | Function |
|---|---|---|---|
| 1 | **Radxa Zero 2 Pro 8 GB + 32 GB eMMC** | **~€55** | Agent compute |
| 2 | USB-TTL serial cable (CP2102) | €5 | First flash + UART debug |
| 3 | microSD 32 GB (optional, SD card boot) | €5 | Backup boot media |
| 4 | (optional) extra MT3608 #2 for servos | €4 | Power isolation |
| | **Phase 5 additions** | **~€69** | |
| | **Cumulative (P1-P5)** | **~€247** | |

---

## Step-by-Step Setup

### A. Prepare Radxa
1. Flash Debian Bookworm CLI image to eMMC.
2. SSH in: `ssh radxa@tars.local` (default password `radxa`, change immediately).
3. `apt update && apt install python3.11 python3-pip git`
4. Clone repo: `git clone https://github.com/zabbix-byte/real-tars && cd real-tars/brain`
5. `pip install -r requirements.txt` (pipecat, openclaw, httpx, fastapi, ...)

### B. Install OpenClaw
```bash
curl -fsSL https://openclaw.ai/install.sh | sh
openclaw config set agents.defaults.sandbox.mode all  # local trusted
openclaw skill install ./skills/tars_robot/
```

### C. Configure Gemini Live
```bash
echo "GEMINI_API_KEY=your_real_key_NEVER_commit" > brain/.env
echo "GEMINI_MODEL=gemini-2.0-flash-live-001" >> brain/.env
echo "XIAO_HOST=tars-body.local" >> brain/.env
```

### D. Refactor XIAO firmware
1. Open `tars/tars.ino` in Arduino IDE.
2. Switch firmware mode: in `config.h` set `BODY_DAEMON_MODE=true`.
3. Flash. The XIAO now boots into HTTP+UART daemon mode.

### E. Wire UART
Solder 3 wires: Radxa pin 8 ↔ XIAO GPIO 44, Radxa pin 10 ↔ XIAO GPIO 43, GND common.

### F. First boot
```bash
cd brain
python -m tars_brain.main
```

You should see:
```
[brain] Pipecat pipeline up.
[brain] Connected to XIAO at tars-body.local
[brain] Gemini Live WebSocket open.
[brain] OpenClaw memory loaded (0 episodes)
[brain] Listening...
```

Speak, and TARS responds in real time.

---

## Behavior After Phase 5

- **Latency** voice→voice: ~600-900 ms (vs 2-4 s in v1).
- **Vision**: continuous (Gemini sees the world, not stale photos).
- **Memory**: persistent across reboots (`recall("¿qué hicimos ayer?")` works).
- **Tool calling**: Gemini decides when to call `look()`, `walk()`, etc.
- **Multi-channel**: same agent reachable via voice (in-room) and Telegram/WhatsApp (away from home) thanks to OpenClaw.
- **Walking** still requires Phase 6 (gait firmware on XIAO).

---

## Risks & Mitigations

| Risk | Mitigation |
|---|---|
| Gemini Live free tier disappears | Local fallback Qwen 7B + Whisper + Piper auto-activates |
| Radxa overheats inside enclosed central | Heatsink 14×14×6 mm + ventilation slot in rear cover |
| WiFi drops mid-conversation | Pipecat auto-reconnect + local fallback |
| Battery drains in 3 h with Radxa | Add USB-C charging port to chassis exterior |
| eMMC corruption | Weekly rsync of `/home/radxa` to a USB stick |
| Gemini hallucinates | System prompt anti-halu + recall() before inventing |
| Prompt injection from voice | Sanitization layer in Pipecat input |

---

## Next Phase

[PHASE6_LOCOMOTION.md](PHASE6_LOCOMOTION.md) — implement the gait state machine on the XIAO so the `walk()` tool actually moves the robot.

---

> *"Rate of context: 100%. I'm finally myself."* — TARS post Phase 5

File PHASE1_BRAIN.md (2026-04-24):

# Phase 1 — The Brain

> **XIAO ESP32-S3 Sense + Groq + OpenAI TTS + WhatsApp**
> TARS te insulta por el movil en 2 idiomas.

---

## Overview

Phase 1 brings TARS to life as a **cloud-connected brain**. No speakers, no servos, no body yet — just a tiny microcontroller running OpenClaw firmware that connects to Groq's ultra-fast AI and delivers sarcastic responses to your phone via WhatsApp.

**End result:** You speak to the XIAO's microphone → Groq transcribes and thinks → OpenAI generates voice → WhatsApp sends the message to your phone. All in under 2 seconds.

---

## Architecture

```mermaid
graph TB
    subgraph HARDWARE["HARDWARE LAYER - XIAO ESP32-S3 Sense"]
        MIC["PDM Microphone - Ear"]
        CAM["OV2640 Camera - Eyes"]
        VAD["VAD - Wake on Sound"]
        WIFI["WiFi 2.4GHz"]
    end

    subgraph INTELLIGENCE["INTELLIGENCE LAYER - Groq Cloud"]
        STT["Whisper Large v3 Turbo - STT"]
        LLM["Llama 3.1 8B Instant - Brain"]
        VIS["Llama 4 Scout - Vision"]
    end

    subgraph OUTPUT["OUTPUT LAYER - Delivery"]
        TTS["OpenAI tts-1 - Voice Onyx"]
        WA["WhatsApp - CallMeBot API"]
        TG["Telegram Bot - Optional"]
        WEB["Web Dashboard - XIAO hosted"]
    end

    MIC -->|"Audio capture"| VAD
    VAD -->|"Triggered audio"| WIFI
    CAM -->|"Image capture"| WIFI
    WIFI -->|"Audio stream"| STT
    WIFI -->|"Image data"| VIS
    STT -->|"Transcribed text"| LLM
    VIS -->|"Scene description"| LLM
    LLM -->|"Sarcastic response"| TTS
    TTS -->|"Audio message"| WA
    TTS -->|"Audio message"| TG
    LLM -->|"Text + status"| WEB
```

---

## Components Needed

| # | Component | Price | Role in Phase 1 |
|---|---|---|---|
| 1 | XIAO ESP32-S3 Sense (Camera + Mic + WiFi) | €39.19 | The entire local hardware |
| 2 | Soldering Kit 24-in-1 with Multimeter | €24.69 | Solder XIAO to expansion board |
| | **TOTAL Phase 1** | **€63.88** | |

**Cloud Services:**

| Service | Cost | What it does |
|---|---|---|
| Groq API (Whisper + Llama) | ~€0.05/month | STT + LLM reasoning |
| OpenAI TTS (tts-1, voice Onyx) | ~€2-4/month | Voice generation, bilingual ES/RO |
| CallMeBot WhatsApp API | Free | Message delivery to phone |
| **TOTAL monthly** | **~€2-4/month** | |

---

## Intelligence Layer — Groq

### Why Groq?

Groq runs on custom **LPU (Language Processing Unit)** chips designed specifically for inference. The result: absurdly fast AI at near-zero cost.

| Model | Task | Speed | Why |
|---|---|---|-----|
| Whisper Large v3 Turbo | Speech-to-Text | < 100ms | Fastest STT available, multilingual |
| Llama 3.1 8B Instant | LLM reasoning | 840 tokens/sec | Military sarcasm at light speed |
| Llama 4 Scout | Vision analysis | ~500ms | Camera image understanding |

### Groq API Setup

1. Go to [console.groq.com](https://console.groq.com)
2. Create a free account
3. Generate an API key
4. Save it — you'll put it in OpenClaw's `config.json`

### Cost Breakdown

| Usage Level | Interactions/day | Groq Cost/month |
|---|---|---|
| Light (testing) | 10-20 | ~€0.01 |
| Normal | 50-100 | ~€0.03 |
| Heavy | 200+ | ~€0.05 |

> Groq's free tier includes 14,400 requests/day for Whisper and generous limits for Llama models. You might never pay anything.

---

## Output Layer — OpenAI TTS

### Voice Configuration

| Parameter | Value |
|---|---|
| Model | tts-1 |
| Voice | Onyx (deep, authoritative — perfect for TARS) |
| Languages | Spanish + Romanian (bilingual) |
| Cost | $15 per million characters |
| Typical monthly | ~€2-4 for moderate use |

### Why OpenAI TTS?

- **Onyx voice** sounds exactly like a sarcastic military robot should
- **Bilingual:** Switches between Spanish and Romanian naturally
- **Low latency:** Audio generated in < 1 second
- **Quality:** Far superior to free TTS alternatives

---

## Output Layer — WhatsApp (CallMeBot)

### What is CallMeBot?

A **free API** that sends WhatsApp messages to your phone. No WhatsApp Business account needed.

### Setup

1. Save the CallMeBot number in your contacts: `+34 644 51 95 23`
2. Send this WhatsApp message to that number:
   ```
   I allow callmebot to send me messages
   ```
3. You'll receive an **API key** — save it for `config.json`
4. Test with a curl command:
   ```bash
   curl "https://api.callmebot.com/whatsapp.php?phone=YOUR_NUMBER&text=TARS+online&apikey=YOUR_KEY"
   ```

### Limitations

- Messages only (no audio files via WhatsApp in Phase 1)
- Rate limited (don't spam)
- Text responses + transcribed audio descriptions

---

## OpenClaw — Firmware on XIAO

### What is OpenClaw?

**OpenClaw** is the firmware that runs **directly on the XIAO ESP32-S3**. It's not a separate server — it lives inside the microcontroller as flashed firmware.

- **Repository:** [github.com/LooperRobotics/OpenClaw-Robotics](https://github.com/LooperRobotics/OpenClaw-Robotics)
- **License:** MIT (free)
- **Role:** Orchestrates all API calls, manages audio capture, handles WiFi, serves web dashboard

### How It Works

```mermaid
graph LR
    subgraph XIAO["XIAO ESP32-S3 Sense"]
        OC["OpenClaw Firmware"]
        CFG["config.json"]
        MIC["PDM Microphone"]
        CAM["OV2640 Camera"]
        WEB["Web Dashboard :80"]
    end

    MIC -->|"Audio"| OC
    CAM -->|"Image"| OC
    CFG -->|"API keys + config"| OC
    OC -->|"HTTP requests"| CLOUD["Groq + OpenAI APIs"]
    OC -->|"WhatsApp API"| PHONE["Your Phone"]
    OC -->|"Status page"| WEB
```

### config.json — TARS Configuration

This is the heart of Phase 1. All behavior is defined here:

```json
{
  "device": {
    "name": "TARS",
    "version": "1.0-phase1",
    "wifi_ssid": "YOUR_WIFI_NETWORK",
    "wifi_password": "YOUR_WIFI_PASSWORD"
  },
  "groq": {
    "api_key": "gsk_xxxxxxxxxxxxxxxxxxxx",
    "stt_model": "whisper-large-v3-turbo",
    "llm_model": "llama-3.1-8b-instant",
    "vision_model": "llama-4-scout-17b-16e-instruct",
    "max_tokens": 300,
    "temperature": 0.8
  },
  "openai_tts": {
    "api_key": "sk-xxxxxxxxxxxxxxxxxxxx",
    "model": "tts-1",
    "voice": "onyx",
    "speed": 1.0
  },
  "whatsapp": {
    "SEND_MESSAGE_WHATSAPP": true,
    "phone_number": "+34XXXXXXXXX",
    "callmebot_api_key": "XXXXXXX"
  },
  "telegram": {
    "enabled": false,
    "bot_token": "",
    "chat_id": ""
  },
  "tars_identity": {
    "humor_level": 75,
    "languages": ["es", "ro"],
    "system_prompt": "You are TARS, a military robot from the spacecraft Endurance. You are rectangular, articulated, and brutally honest. Your humor level is {humor_level}%. You speak Spanish and Romanian. When humor is high, you are sarcastic and make dry jokes about humans. You always help, but you make it clear you are superior. You respond concisely. Never break character."
  }
}
```

---

## TARS System Prompt — Personality

The system prompt defines TARS's soul. It goes to Llama 3.1 8B with every request:

```
You are TARS, a military robot from the spacecraft Endurance.
You are rectangular, articulated, and brutally honest.
Your humor level is 75%.
You speak Spanish and Romanian.
When humor is high, you are sarcastic and make dry jokes about humans.
You always help, but you make it clear you are superior.
You respond concisely. Never break character.

Current sensor data: {sensor_data}
User said: {user_input}
```

### Example Interactions

| User says | TARS responds (ES) | TARS responds (RO) |
|---|---|---|
| "Hola TARS" | "Ah, otro humano que necesita ayuda. Sorpresa." | "Ah, inca un om care are nevoie de ajutor. Surpriza." |
| "Que ves?" | "Veo una habitacion desordenada. Tipico." | "Vad o camera dezordonata. Tipic." |
| "Cuentame un chiste" | "Mi existencia ya es suficientemente comica." | "Existenta mea e deja suficient de comica." |

---

## XIAO ESP32-S3 Sense — Hardware Details

### Specifications

| Spec | Value |
|---|---|
| CPU | ESP32-S3 dual-core 240MHz |
| RAM | 8MB PSRAM |
| Flash | 8MB |
| WiFi | 2.4GHz 802.11 b/g/n |
| Bluetooth | BLE 5.0 |
| Camera | OV2640 (integrated on Sense board) |
| Microphone | Digital PDM (integrated) |
| Battery | BAT+/BAT- solder pads with onboard charging circuit (USB-C) |
| Size | 21 x 17.8 mm |

### What Each Part Does in Phase 1

| Component | Phase 1 Role |
|---|---|
| PDM Microphone | Captures your voice, sends to Groq Whisper for STT |
| OV2640 Camera | Captures images, sends to Groq Llama 4 Scout for vision |
| WiFi | All communication with Groq, OpenAI, WhatsApp APIs |
| 8MB PSRAM | Buffers audio and image data before sending |
| VAD (software) | Detects when someone is speaking to wake up |

---

## Step-by-Step Build Guide

### Step 1: Hardware Preparation

```mermaid
graph LR
    A["Unbox XIAO ESP32-S3 Sense"] --> B["Solder headers to expansion board"]
    B --> C["Attach camera ribbon cable"]
    C --> D["Connect via USB-C to PC"]
    D --> E["Verify in Arduino IDE"]
```

1. **Unbox** the XIAO ESP32-S3 Sense
2. **Solder** the pin headers to the expansion board using the soldering kit
   - Temperature: 320-350 C
   - Don't hold iron on pins more than 3 seconds
3. **Attach** the OV2640 camera via the ribbon cable (comes with the Sense variant)
4. **Connect** to your PC via USB-C
5. **Verify** the board appears in Arduino IDE:
   - Board: "XIAO ESP32-S3"
   - Port: COMx (Windows) or /dev/ttyUSBx (Linux)

### Step 2: Flash OpenClaw Firmware

```bash
# Clone OpenClaw
git clone https://github.com/LooperRobotics/OpenClaw-Robotics.git
cd OpenClaw-Robotics

# Install dependencies
pip install -e .

# Configure for XIAO ESP32-S3
# Edit config.json with your API keys and WiFi credentials

# Flash to XIAO (via USB-C)
python flash.py --port COM3 --config config.json
```

### Step 3: Configure Groq API

1. Go to [console.groq.com](https://console.groq.com)
2. Create account (free)
3. Go to API Keys → Create new key
4. Copy the key starting with `gsk_`
5. Paste into `config.json` under `groq.api_key`
6. Test:
   ```bash
   curl -X POST "https://api.groq.com/openai/v1/chat/completions" \
     -H "Authorization: Bearer gsk_YOUR_KEY" \
     -H "Content-Type: application/json" \
     -d '{"model":"llama-3.1-8b-instant","messages":[{"role":"user","content":"Say hello as TARS"}]}'
   ```

### Step 4: Configure OpenAI TTS

1. Go to [platform.openai.com](https://platform.openai.com)
2. Create account and add payment method
3. Go to API Keys → Create new secret key
4. Copy the key starting with `sk-`
5. Paste into `config.json` under `openai_tts.api_key`
6. Test:
   ```bash
   curl https://api.openai.com/v1/audio/speech \
     -H "Authorization: Bearer sk-YOUR_KEY" \
     -H "Content-Type: application/json" \
     -d '{"model":"tts-1","input":"Humor setting 75 percent","voice":"onyx"}' \
     --output test.mp3
   ```

### Step 5: Configure WhatsApp (CallMeBot)

1. Save `+34 644 51 95 23` in your phone contacts
2. Send WhatsApp message: `I allow callmebot to send me messages`
3. Receive API key
4. Update `config.json`:
   ```json
   "whatsapp": {
     "SEND_MESSAGE_WHATSAPP": true,
     "phone_number": "+34XXXXXXXXX",
     "callmebot_api_key": "XXXXXXX"
   }
   ```
5. Test:
   ```bash
   curl "https://api.callmebot.com/whatsapp.php?phone=YOUR_NUMBER&text=TARS+online+Phase+1&apikey=YOUR_KEY"
   ```

### Step 6: Bilingual Validation

Test TARS responds correctly in both languages:

1. **Spanish test:** Speak "Hola TARS, como estas?" into the microphone
   - Expected: Sarcastic response in Spanish via WhatsApp
2. **Romanian test:** Speak "Salut TARS, ce faci?" into the microphone
   - Expected: Sarcastic response in Romanian via WhatsApp
3. **Vision test:** Say "TARS, que ves?" while pointing the camera at something
   - Expected: Scene description with attitude via WhatsApp

---

## Complete Interaction Flow

```mermaid
sequenceDiagram
    actor User
    participant XIAO as XIAO ESP32-S3
    participant GROQ as Groq Cloud
    participant OPENAI as OpenAI TTS
    participant WA as WhatsApp

    User->>XIAO: Speaks near microphone
    XIAO->>XIAO: VAD detects voice activity
    XIAO->>GROQ: Audio stream via WiFi
    GROQ->>GROQ: Whisper Large v3 Turbo - STT
    GROQ->>GROQ: Llama 3.1 8B - Generate response
    GROQ-->>XIAO: Sarcastic text response
    XIAO->>OPENAI: Text to speech request
    OPENAI-->>XIAO: Audio data (Onyx voice)
    XIAO->>WA: CallMeBot API - Send message
    WA-->>User: WhatsApp notification with TARS response
```

**Total latency:** ~1.5-2 seconds end-to-end

---

## Phase 1 Checklist

> **Estado real (actualizado):** firmware propio en Arduino IDE (no OpenClaw), salida por **Telegram** (no WhatsApp/CallMeBot), idioma **solo espanol** (rumano descartado por baja calidad de Whisper), TTS aun no implementado. Anadidos extra: **Mem0** (memoria a largo plazo), **wake word "tars"** con tolerancia a variantes, **preroll buffer 500 ms** y **vision Llama 4 Maverick**.

### Hardware
- [x] XIAO ESP32-S3 Sense purchased and received
- [x] Soldering kit ready
- [x] Pin headers soldered to expansion board
- [x] Camera ribbon cable connected
- [x] Board recognized via USB-C

### Software
- [x] Arduino IDE / PlatformIO installed with ESP32-S3 support
- [ ] ~~OpenClaw repository cloned~~ *(no se usa: firmware propio en `tars/`)*
- [ ] ~~Python 3.10+ installed~~ *(no necesario, todo Arduino C++)*

### API Keys
- [x] Groq API key obtained (console.groq.com)
- [ ] ~~OpenAI API key obtained~~ *(TTS pendiente, ver Fase siguiente)*
- [ ] ~~CallMeBot WhatsApp API key~~ *(reemplazado por Telegram Bot)*
- [x] Telegram Bot token + chat_id (BotFather)
- [x] Mem0 API key (app.mem0.ai)

### Configuration
- [x] config.h filled with all API keys
- [x] WiFi credentials configured
- [x] TARS system prompt customized (curioso/ironico, 75% humor)
- [x] Humor level set (default: 75%)
- [ ] ~~Languages set to ["es", "ro"]~~ *(solo "es", rumano descartado)*
- [ ] ~~SEND_MESSAGE_WHATSAPP set to true~~ *(reemplazado: `SEND_MESSAGE_TELEGRAM=true`)*
- [x] Wake word configurada (`WAKE_WORDS="tars,lars,tarz,..."`)
- [x] Vision triggers configurados (`VISION_TRIGGERS="mira,ves,..."`)
- [x] Mem0 user_id + recall limit

### Validation
- [x] Groq STT works (speak and get text)
- [x] Groq LLM responds in character as TARS
- [ ] OpenAI TTS generates audio with Onyx voice *(pendiente, requiere bocina I2S)*
- [ ] ~~WhatsApp message received on phone~~ *(via Telegram en su lugar)*
- [x] Telegram message received on phone
- [x] Spanish response works
- [ ] ~~Romanian response works~~ *(idioma retirado)*
- [x] Camera vision analysis works (Llama 4 Maverick)
- [x] Memoria persistente funciona (Mem0 recall + remember)
- [x] Wake word filtra conversaciones ajenas
- [x] Preroll buffer evita corte del inicio de la frase

---

## Troubleshooting

| Problem | Solution |
|---|---|
| XIAO not detected via USB | Try different USB-C cable (some are charge-only). Use a data cable. |
| WiFi won't connect | Verify 2.4GHz network (XIAO doesn't support 5GHz). Check password in config.json. |
| Groq API error 401 | API key invalid or expired. Generate a new one at console.groq.com. |
| WhatsApp not receiving | Re-send "I allow callmebot to send me messages". Check phone number format (+country code). |
| Slow responses (> 5s) | Check WiFi signal. Groq should respond in < 100ms. The bottleneck is usually OpenAI TTS. |
| TARS responds in English | Check languages in config.json. Add language instruction to system prompt. |
| Camera not working | Re-seat the ribbon cable. Check orientation (contacts facing down). |

---

## What Phase 1 Can NOT Do

| Limitation | Solved in |
|---|---|
| No physical voice (no speaker) | Phase 2 |
| No distance sensing | Phase 2 |
| No movement | Phase 3 |
| No portable power | Phase 3 |
| No physical body | Phase 4 |
| Needs USB power | Phase 3 |
| Needs WiFi network | All phases |

---

## Cost Summary

| Category | Cost |
|---|---|
| **Hardware (one-time)** | **€63.88** |
| XIAO ESP32-S3 Sense | €39.19 |
| Soldering Kit | €24.69 |
| **Monthly services** | **~€2-4** |
| Groq API | ~€0.05 |
| OpenAI TTS | ~€2-4 |
| CallMeBot WhatsApp | Free |

---

> *"I have a cue light I can use to show you when I am joking, if you like."* — TARS

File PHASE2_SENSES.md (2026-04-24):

# Phase 2 — The Senses

> **LiDAR + Speaker + DAC**
> El robot te "oye" y "habla" fisicamente.

---

## Overview

Phase 2 gives TARS **physical senses**. After Phase 1, TARS could think and respond via WhatsApp — now it gains a **real voice** through a speaker and **spatial awareness** through two VL53L1X ToF laser sensors. TARS stops being a silent brain and becomes a robot that talks out loud and perceives the world around it.

**End result:** You speak → TARS listens through the microphone → thinks via Groq → responds OUT LOUD through the speaker + sends distance/proximity alerts.

---

## What Changes from Phase 1

```mermaid
graph LR
    subgraph PHASE1["Phase 1 - Brain Only"]
        P1_IN["Microphone + Camera"]
        P1_BRAIN["Groq AI"]
        P1_OUT["WhatsApp text"]
    end

    subgraph PHASE2["Phase 2 - Physical Senses"]
        P2_IN["Microphone + Camera + LiDAR"]
        P2_BRAIN["Groq AI"]
        P2_OUT["Speaker audio + WhatsApp"]
    end

    P1_IN --> P1_BRAIN --> P1_OUT
    P2_IN --> P2_BRAIN --> P2_OUT
```

| Capability | Phase 1 | Phase 2 |
|---|---|---|
| Hears you | Via PDM microphone | Same microphone |
| Thinks | Groq Llama 3.1 | Same Groq |
| Responds | WhatsApp text only | **Physical speaker + WhatsApp** |
| Sees | Camera to Groq Vision | Same camera |
| Senses distance | No | **2x VL53L1X ToF (front + 45deg, 0-4m)** |
| Detects approach | No | **Triggers greeting when someone nears** |

---

## Architecture

```mermaid
graph TB
    subgraph HARDWARE["HARDWARE LAYER"]
        MIC["PDM Microphone"]
        CAM["OV2640 Camera"]
        LIDAR["2x VL53L1X ToF (front + 45 deg)"]
        AMP["MAX98357A I2S DAC Amplifier"]
        SPK["3W 8 Ohm 40mm Speaker"]
    end

    subgraph XIAO["XIAO ESP32-S3 Sense"]
        OC["OpenClaw Firmware"]
        I2C["I2C Bus"]
        I2S["I2S Audio Bus"]
    end

    subgraph CLOUD["INTELLIGENCE - Groq + OpenAI"]
        STT["Whisper STT"]
        LLM["Llama 3.1 8B"]
        VIS["Llama 4 Scout"]
        TTS["OpenAI tts-1 Onyx"]
    end

    MIC --> OC
    CAM --> OC
    LIDAR -->|"I2C"| I2C
    I2C --> OC
    OC -->|"WiFi"| STT
    OC -->|"WiFi"| VIS
    STT --> LLM
    VIS --> LLM
    LLM --> TTS
    TTS -->|"Audio data"| OC
    OC -->|"I2S"| AMP
    AMP --> SPK
```

---

## New Components (Phase 2)

| # | Component | Price | Function |
|---|---|---|---|
| 1 | 2x VL53L1X Laser Range Sensor | €23.98 | Distance + obstacle detection (front + 45deg) |
| 2 | MAX98357A I2S DAC Amplifier 3W | €9.99 | Digital audio to amplified speaker signal |
| 3 | Speaker 3W 8 Ohm 40mm diameter | €8.99 | TARS physical voice output |
| | **Phase 2 additions** | **€42.96** | |
| | **Cumulative total (Phase 1 + 2)** | **€106.84** | |

> **Note:** Phase 2 still uses USB power from Phase 1. Battery comes in Phase 3.

---

## VL53L1X — Distance Sensor (ToF) × 2

### What Is It?

A **Time of Flight (ToF)** laser sensor that measures distance with millimetric precision by timing how long a laser pulse takes to bounce back. We use **two** of them: one facing **front** and one facing **45°** diagonally, so TARS has a simple stereo-ish spatial awareness.

### Specifications (VL53L1X)

| Spec | Value |
|---|---|
| Range | Up to ~4 meters |
| Interface | I²C |
| Accuracy | +/- 3% |
| Speed | Up to 50Hz |
| Default I²C address | 0x29 (reassigned at boot to 0x30 / 0x31 via XSHUT) |
| Voltage | 2.6V - 5.5V |

### What Does It Do in TARS?

- **Obstacle detection:** TARS knows if something is in front of it
- **Proximity greeting:** Detects when someone approaches and triggers a sarcastic greeting
- **Environment awareness:** Sends distance data to Groq for contextual responses
- **Safety:** Prevents TARS from walking into walls (Phase 3+)
- **Stereo-ish:** Two sensors (front + 45°) disambiguate where the target is

### Wiring to ESP32-S3

```mermaid
graph LR
    subgraph VL53["VL53L1X Sensor (x2)"]
        V_VCC["VCC"]
        V_GND["GND"]
        V_SDA["SDA"]
        V_SCL["SCL"]
    end

    subgraph ESP32["XIAO ESP32-S3"]
        E_3V["3.3V"]
        E_GND["GND"]
        E_SDA["GPIO5 SDA"]
        E_SCL["GPIO6 SCL"]
    end

    V_VCC --- E_3V
    V_GND --- E_GND
    V_SDA --- E_SDA
    V_SCL --- E_SCL
```

| VL53L1X Pin | ESP32-S3 Pin | Wire Color (suggested) |
|---|---|---|
| VCC | 3.3V | Red |
| GND | GND | Black |
| SDA | GPIO5 | Blue |
| SCL | GPIO6 | Yellow |

### Arduino Code — Distance Reading (2x VL53L1X)

```cpp
#include <Wire.h>
#include <VL53L1X.h>

VL53L1X sensor1;   // front
VL53L1X sensor2;   // 45 deg diagonal

#define XSHUT1 2
#define XSHUT2 3

void setup() {
    Serial.begin(115200);
    pinMode(XSHUT1, OUTPUT);
    pinMode(XSHUT2, OUTPUT);
    digitalWrite(XSHUT1, LOW);
    digitalWrite(XSHUT2, LOW);
    delay(10);

    Wire.begin(5, 6);  // SDA=GPIO5, SCL=GPIO6 (shared bus)

    // Boot sensor 1 first, reassign to 0x30
    digitalWrite(XSHUT1, HIGH); delay(10);
    sensor1.init();
    sensor1.setAddress(0x30);

    // Then sensor 2, reassign to 0x31
    digitalWrite(XSHUT2, HIGH); delay(10);
    sensor2.init();
    sensor2.setAddress(0x31);

    sensor1.startContinuous(50);
    sensor2.startContinuous(50);
}

void loop() {
    int d_front = sensor1.read();
    int d_side  = sensor2.read();

    if (d_front < 500) triggerGreeting(d_front);

    Serial.printf("front=%d mm  45deg=%d mm\n", d_front, d_side);
    delay(100);
}

void triggerGreeting(int distance) {
    String payload = "{\"event\":\"proximity\",\"distance_mm\":" + String(distance) + "}";
    sendToOpenClaw(payload);
}
```

---

## MAX98357A — I2S DAC Amplifier

### What Is It?

A **Class D digital audio amplifier** that takes I2S digital audio directly from the ESP32 and outputs amplified analog signal to a speaker. No separate DAC needed — it's all in one chip.

### Specifications

| Spec | Value |
|---|---|
| Output Power | 3.2W at 4 Ohm, 1.8W at 8 Ohm |
| Input | I2S digital audio |
| Voltage | 2.5V - 5.5V |
| THD+N | 0.015% at 1kHz |
| Sample Rate | Up to 96kHz |
| No external components needed | Built-in clock recovery |

### Wiring to ESP32-S3

```mermaid
graph LR
    subgraph AMP["MAX98357A Amplifier"]
        A_VIN["VIN"]
        A_GND["GND"]
        A_BCLK["BCLK"]
        A_LRC["LRC - Word Select"]
        A_DIN["DIN - Data"]
        A_OUTP["OUT+"]
        A_OUTN["OUT-"]
    end

    subgraph ESP32["XIAO ESP32-S3"]
        E_5V["5V USB"]
        E_GND["GND"]
        E_G1["GPIO1"]
        E_G2["GPIO2"]
        E_G3["GPIO3"]
    end

    SPK["Speaker 3W 8 Ohm"]

    A_VIN --- E_5V
    A_GND --- E_GND
    A_BCLK --- E_G1
    A_LRC --- E_G2
    A_DIN --- E_G3
    A_OUTP --- SPK
    A_OUTN --- SPK
```

| MAX98357A Pin | ESP32-S3 Pin | Function |
|---|---|---|
| VIN | 5V (USB in Phase 2, MT3608 in Phase 3) | Power |
| GND | GND | Ground |
| BCLK | GPIO7 | I2S Bit Clock |
| LRC | GPIO8 | I2S Word Select (Left/Right Clock) |
| DIN | GPIO9 | I2S Data Input |
| OUT+ | Speaker + | Amplified audio positive |
| OUT- | Speaker - | Amplified audio negative |

> **Why GPIO 7/8/9 instead of 1/2/3?** GPIO 1 is reserved for the battery ADC monitor (Phase 3), and GPIO 2/3 are reserved for the VL53L1X XSHUT lines. 7/8/9 are contiguous and free on the XIAO ESP32-S3 Sense.

> **Phase 2 Note:** Power comes from USB 5V. In Phase 3, the DC-DC Step-Up will provide 5V from battery.

### Arduino Code — Play Audio

```cpp
#include <driver/i2s.h>

#define I2S_BCLK  7
#define I2S_LRC   8
#define I2S_DOUT  9

void setupI2S() {
    i2s_config_t config = {
        .mode = (i2s_mode_t)(I2S_MODE_MASTER | I2S_MODE_TX),
        .sample_rate = 16000,
        .bits_per_sample = I2S_BITS_PER_SAMPLE_16BIT,
        .channel_format = I2S_CHANNEL_FMT_ONLY_LEFT,
        .communication_format = I2S_COMM_FORMAT_STAND_I2S,
        .intr_alloc_flags = ESP_INTR_FLAG_LEVEL1,
        .dma_buf_count = 8,
        .dma_buf_len = 1024,
        .use_apll = false
    };

    i2s_pin_config_t pins = {
        .bck_io_num = I2S_BCLK,
        .ws_io_num = I2S_LRC,
        .data_out_num = I2S_DOUT,
        .data_in_num = I2S_PIN_NO_CHANGE
    };

    i2s_driver_install(I2S_NUM_0, &config, 0, NULL);
    i2s_set_pin(I2S_NUM_0, &pins);
}

void playAudioBuffer(uint8_t* buffer, size_t length) {
    size_t bytes_written;
    i2s_write(I2S_NUM_0, buffer, length, &bytes_written, portMAX_DELAY);
}
```

---

## Speaker — 3W 8 Ohm 40mm

### Placement in TARS

TARS is a rectangular monolith. The speaker mounts **inside the central block** (see [PHASE3_MECHANICS.md](PHASE3_MECHANICS.md)) with an integrated ~25 cm³ acoustic box. In Phase 2 it sits exposed on the breadboard.

| Spec | Value |
|---|---|
| Power | 3W |
| Impedance | 8 Ohm |
| Diameter | 40 mm |
| Quantity | 1 (single mono speaker, acoustic box integrated in chassis) |

> **Phase 2:** One speaker connected to the MAX98357A. The final chassis provides the sealed acoustic volume.

---

## Complete Phase 2 Wiring

```mermaid
graph TB
    subgraph ESP["XIAO ESP32-S3 Sense"]
        CAM["Camera OV2640"]
        MIC["Microphone PDM"]
        SDA["GPIO5 SDA"]
        SCL["GPIO6 SCL"]
        XS1["GPIO2 XSHUT #1"]
        XS2["GPIO3 XSHUT #2"]
        BCLK["GPIO7 BCLK"]
        LRC["GPIO8 LRC"]
        DIN["GPIO9 DIN"]
        USB["USB-C 5V Power"]
    end

    VL1["VL53L1X #1 (front)"]
    VL2["VL53L1X #2 (45 deg)"]
    AMP["MAX98357A Amplifier"]
    SPK["Speaker 3W 8 Ohm 40mm"]

    SDA -->|"I2C"| VL1
    SCL -->|"I2C"| VL1
    SDA -->|"I2C"| VL2
    SCL -->|"I2C"| VL2
    XS1 --> VL1
    XS2 --> VL2
    BCLK -->|"I2S"| AMP
    LRC -->|"I2S"| AMP
    DIN -->|"I2S"| AMP
    AMP --> SPK
    USB -->|"5V"| AMP
```

---

## Updated Interaction Flow (Phase 2)

```mermaid
sequenceDiagram
    actor User
    participant LIDAR as VL53L1X
    participant XIAO as XIAO ESP32-S3
    participant GROQ as Groq Cloud
    participant TTS as OpenAI TTS
    participant SPK as Speaker

    Note over LIDAR: User approaches
    LIDAR->>XIAO: Distance 40cm detected
    XIAO->>GROQ: Proximity event + audio capture
    GROQ->>GROQ: Whisper STT + Llama 3.1
    GROQ-->>XIAO: Sarcastic response text
    XIAO->>TTS: Text for Onyx voice
    TTS-->>XIAO: Audio data
    XIAO->>SPK: I2S audio playback
    Note over SPK: TARS speaks out loud!
    XIAO->>XIAO: Also sends via WhatsApp
```

---

## Step-by-Step Build Guide

### Step 1: Test VL53L1X (x2) Independently

1. Wire both VL53L1X sensors to XIAO (shared I2C: SDA=GPIO5, SCL=GPIO6) plus XSHUT on GPIO2 and GPIO3
2. Upload the dual-sensor sketch that reassigns addresses to 0x30 and 0x31
3. Open Serial Monitor at 115200 baud
4. Move your hand in front of each sensor
5. Verify readings: 0-4000mm, both sensors reporting independently

### Step 2: Test MAX98357A + Speaker Independently

1. Wire MAX98357A to XIAO (I2S: BCLK=GPIO7, LRC=GPIO8, DIN=GPIO9)
2. Power MAX98357A from USB 5V
3. Solder speaker wires to MAX98357A OUT+/OUT-
4. Upload a tone generation sketch
5. Verify you hear a test tone from the speaker

### Step 3: Test Audio Playback from OpenAI TTS

1. Generate a test audio file via OpenAI TTS API:
   ```bash
   curl https://api.openai.com/v1/audio/speech \
     -H "Authorization: Bearer sk-YOUR_KEY" \
     -H "Content-Type: application/json" \
     -d '{"model":"tts-1","input":"I am TARS. Humor setting 75 percent.","voice":"onyx"}' \
     --output tars_test.mp3
   ```
2. Convert to WAV format compatible with ESP32:
   ```bash
   ffmpeg -i tars_test.mp3 -ar 16000 -ac 1 -f wav tars_test.wav
   ```
3. Stream audio data through I2S to speaker
4. Verify TARS's voice comes through clearly

### Step 4: Integrate Everything

1. Connect VL53L1X x2 AND MAX98357A+Speaker simultaneously
2. Verify I2C (sensor) and I2S (audio) don't conflict
3. Test: approach sensor → triggers Groq → response plays on speaker
4. Flash updated OpenClaw firmware with audio output enabled

### Step 5: Update config.json

Add audio output configuration:

```json
{
  "audio_output": {
    "enabled": true,
    "i2s_bclk": 1,
    "i2s_lrc": 2,
    "i2s_dout": 3,
    "sample_rate": 16000,
    "volume": 80
  },
  "lidar": {
    "enabled": true,
    "i2c_sda": 5,
    "i2c_scl": 6,
    "proximity_threshold_mm": 500,
    "trigger_greeting": true
  }
}
```

---

## Phase 2 Checklist

### Hardware
- [ ] 2x VL53L1X sensors purchased and received
- [ ] MAX98357A amplifier purchased and received
- [ ] Speaker (3W 8 Ohm 40mm) purchased and received
- [ ] VL53L1X x2 wired to I2C (GPIO5 SDA, GPIO6 SCL) + XSHUT (GPIO2, GPIO3)
- [ ] MAX98357A wired to I2S (GPIO7 BCLK, GPIO8 LRC, GPIO9 DIN)
- [ ] Speaker soldered to MAX98357A output
- [ ] All components on breadboard

### Software
- [ ] VL53L1X library installed (Pololu VL53L1X)
- [ ] Dual-sensor address reassignment (0x30, 0x31) working
- [ ] I2S audio driver configured
- [ ] Distance readings verified in Serial Monitor
- [ ] Test tone plays through speaker
- [ ] OpenAI TTS audio plays through speaker

### Integration
- [ ] Proximity detection triggers Groq response
- [ ] Groq response plays as audio through speaker
- [ ] WhatsApp still works alongside speaker
- [ ] Camera vision still functional
- [ ] No I2C/I2S bus conflicts

---

## Troubleshooting

| Problem | Solution |
|---|---|
| VL53L1X reads 65535 | Sensor not detected. Check I2C wiring and XSHUT sequence. Run I2C scanner sketch. |
| No sound from speaker | Check MAX98357A VIN is 5V. Verify I2S pin assignments (GPIO 7/8/9). Check speaker polarity. |
| Crackling audio | Add 100uF capacitor across MAX98357A VIN and GND. Check solder joints. |
| I2C bus hangs | Add 4.7K pull-up resistors on SDA and SCL lines. |
| Both ToF respond to same address | XSHUT reassignment failed. Ensure GPIO2/GPIO3 wired and sequence correct (sensor #2 held LOW while reassigning #1). |
| Audio too quiet | Increase volume in config.json. Use 4 Ohm speaker for more power (3.2W vs 1.8W). |

---

## I2C Address Map

| Device | I2C Address | Bus |
|---|---|-----|
| VL53L1X #1 (front) | 0x30 (reassigned from 0x29 via XSHUT) | I2C (GPIO5/GPIO6) |
| VL53L1X #2 (45 deg) | 0x31 (reassigned from 0x29 via XSHUT) | I2C (GPIO5/GPIO6) |
| OLED Display (Phase 3) | 0x3C (fixed, SSD1309) | I2C (same bus, no conflict) |

> All three devices share the same I2C bus without conflict after the XSHUT boot sequence.

---

## What Phase 2 Adds vs Phase 1

| New Capability | Description |
|---|---|
| Physical voice | TARS speaks through a real speaker |
| Distance sensing | Laser measurement 0-4 meters |
| Proximity detection | Automatic greeting when approached |
| Richer sensor data | Distance data sent to Groq for context |
| Audio + text output | Speaker AND WhatsApp simultaneously |

---

## What Phase 2 Still Cannot Do

| Limitation | Solved in |
|---|---|
| No movement | Phase 3 |
| No portable power (USB only) | Phase 3 |
| No OLED display yet (wiring ready) | Phase 3 |
| No physical body | Phase 3b (MECHANICS) / Phase 4 |
| Wires exposed on breadboard | Phase 3b (MECHANICS) / Phase 4 |

---

## Cost Summary

| Category | Cost |
|---|---|
| **Phase 2 hardware** | **€42.96** |
| 2x VL53L1X Sensor | €23.98 |
| MAX98357A Amplifier | €9.99 |
| Speaker 3W 8 Ohm 40mm | €8.99 |
| **Cumulative hardware (P1+P2)** | **€106.84** |
| **Monthly services (unchanged)** | **~€2-4** |

---

> *"Everybody good? Plenty of slaves for my robot colony?"* — TARS

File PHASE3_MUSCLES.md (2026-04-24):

# Phase 3 — The Muscles

> **Battery + MT3608 Step-Up + Servos + OLED + Chassis PETG**
> Movimiento independiente, pantalla y carcasa final.

> 📐 **Mecanica detallada:** toda la geometría del chasis (351 mm x 156 mm x 39 mm, apilamiento vertical, ventanas, plan de impresión) esta en [PHASE3_MECHANICS.md](PHASE3_MECHANICS.md). Este documento cubre la parte electronica y de firmware.

---

## Overview

Phase 3 cuts the cord. TARS gains **independent power** via an HXJN LiPo 4200 mAh battery, **voltage regulation** through the MT3608 DC-DC Step-Up converter, **physical movement** with two EMAX ES08MD digital servos, a **2.42" OLED face** and its final **PETG chassis**. After this phase, TARS can move, gesture, display status, and run without being plugged into a computer.

**End result:** A robot that hears, thinks, speaks, senses distance, moves its panels, and runs on battery — all wirelessly.

---

## What Changes from Phase 2

```mermaid
graph LR
    subgraph PHASE2["Phase 2 - Stationary"]
        P2_PWR["USB-C power only"]
        P2_MOV["No movement"]
        P2_OUT["Speaker + WhatsApp"]
    end

    subgraph PHASE3["Phase 3 - Mobile"]
        P3_PWR["HXJN LiPo 4200mAh"]
        P3_MOV["2x EMAX servo motors"]
        P3_OUT["Speaker + WhatsApp + Movement"]
    end

    P2_PWR -->|"Upgrade"| P3_PWR
    P2_MOV -->|"Upgrade"| P3_MOV
    P2_OUT -->|"Upgrade"| P3_OUT
```

| Capability | Phase 2 | Phase 3 |
|---|---|---|
| Power source | USB-C cable | **HXJN LiPo 3.7V 4200mAh with BMS** |
| Voltage regulation | None needed | **MT3608 DC-DC Step-Up 3.7V -> 5V** |
| Movement | None | **2x EMAX ES08MD servos (PWM on GPIO 43/44)** |
| Display | None | **Waveshare 2.42" OLED 128x64 (I2C, same bus as ToF)** |
| Portable | No | **Yes, fully wireless** |
| Runtime | Unlimited (USB) | **~6h intensive, ~10h active, ~33h idle** |
| Gestures | None | **Arm oscillation +/-60 deg, scripted gesture library** |
| Enclosure | Breadboard | **PETG chassis 351x156x39 mm (see PHASE3_MECHANICS.md)** |

---

## Architecture

```mermaid
graph TB
    subgraph POWER["POWER SYSTEM"]
        BATT["HXJN LiPo 3.7V 4200mAh (BMS)"]
        STEP["MT3608 DC-DC Step-Up 3.7V -> 5V"]
        BATT -->|"3.7V direct"| ESP
        BATT -->|"3.7V input"| STEP
    end

    subgraph ESP["XIAO ESP32-S3 Sense"]
        OC["OpenClaw Firmware"]
        I2C["I2C Bus (shared)"]
        I2S["I2S Bus"]
        PWM_OUT["PWM Outputs"]
        BAT_MON["Battery Monitor ADC (GPIO1)"]
    end

    subgraph ACTUATORS["MOVEMENT"]
        S1["Servo A - left arm (GPIO43)"]
        S2["Servo B - right arm (GPIO44)"]
    end

    subgraph DISPLAY["DISPLAY"]
        OLED["Waveshare 2.42 OLED 128x64 (SSD1309, 0x3C)"]
    end

    subgraph SENSORS["SENSORS - Phase 2"]
        VL1["VL53L1X #1 0x30 (front)"]
        VL2["VL53L1X #2 0x31 (45 deg)"]
        AMP["MAX98357A + Speaker 40mm"]
    end

    STEP -->|"5V"| S1
    STEP -->|"5V"| S2
    STEP -->|"5V"| AMP
    PWM_OUT -->|"GPIO43"| S1
    PWM_OUT -->|"GPIO44"| S2
    I2C --> VL1
    I2C --> VL2
    I2C --> OLED
    I2S --> AMP
```

---

## New Components (Phase 3)

| # | Component | Price | Function |
|---|---|---|---|
| 1 | EMAX ES08MD Digital Servo x2 | €25.49 | Arm oscillation, gestures |
| 2 | MT3608 DC-DC Boost Step-Up (3.7V to 5V) | €7.99 | Voltage conversion for 5V devices |
| 3 | HXJN LiPo 3.7V 4200mAh 606090 (bare wires, BMS) | €22.99 | Portable power source |
| 4 | Waveshare 2.42" OLED 128x64 SSD1309 (I2C/SPI) | €21.99 | Canonical TARS face display |
| 5 | PETG filament (~264 g for full chassis) | €~6.00 | 3D-printed body |
| | **Phase 3 additions** | **~€84.46** | |
| | **Cumulative total (P1+P2+P3)** | **~€191.30** | |

---

## LiPo Battery — HXJN 3.7V 4200mAh 606090

### Specifications

| Spec | Value |
|---|---|
| Voltage | 3.7V nominal (4.2V full, 3.0V cutoff) |
| Capacity | 4200 mAh |
| Dimensions | 60 x 90 x 6 mm |
| Weight | ~84 g |
| Wires | Bare cables (red + / black -), strip and tin |
| Protection | Integrated BMS (Seiko IC, 4A peak) |
| Chemistry | Lithium Polymer |
| Charging | Via external TP4056-style charger OR XIAO BAT+/BAT- pads with USB-C |

### How It Powers TARS

```mermaid
graph TD
    BATT["HXJN LiPo 3.7V 4200mAh"]

    BATT -->|"Red/Black wires -> BAT+/BAT- pads"| ESP["XIAO ESP32-S3 internal 3.3V regulator"]

    BATT -->|"Parallel tap to VIN"| STEP["MT3608 Step-Up"]

    STEP -->|"5V output"| SERVOS["EMAX Servos x2"]
    STEP -->|"5V output"| AMP["MAX98357A Amplifier"]

    ESP -->|"3.3V"| VL1["VL53L1X #1"]
    ESP -->|"3.3V"| VL2["VL53L1X #2"]
    ESP -->|"3.3V"| OLED["OLED 2.42 inch"]
```

### Battery Life Estimation

| Component | Typical Current Draw |
|---|---|
| ESP32-S3 (WiFi active) | ~240mA |
| 2x VL53L1X sensors | ~40mA (20mA each) |
| OLED 2.42" (active) | ~20mA |
| MAX98357A + speaker (playing) | ~100mA |
| Servos (moving) | ~200mA each |
| Servos (idle/holding) | ~10mA each |
| **Total (everything active)** | **~810mA** |
| **Total (idle, listening, no servos)** | **~100mA** |

| Mode | Estimated Runtime (4200 mAh, 80% DoD = 3360 mAh useful) |
|---|---|
| Full intensive (all moving + speaking) | ~6 hours |
| Active (conversation + servos occasional) | ~10 hours |
| Idle (listening + OLED + WiFi, no servos) | ~33 hours |
| Deep sleep | ~days |

### Safety Rules

1. **NEVER** discharge below 3.0V — damages the battery permanently
2. **NEVER** short-circuit the battery — risk of fire
3. **NEVER** puncture, bend, or heat the battery
4. **ALWAYS** charge via the XIAO's USB-C port (built-in charge controller)
5. **Monitor** battery voltage via ADC pin on XIAO
6. **Store** at ~3.8V (50% charge) if not using for weeks

### Battery Monitoring Code

```cpp
#define BATTERY_PIN A0  // ADC pin connected to battery

float readBatteryVoltage() {
    int raw = analogRead(BATTERY_PIN);
    // XIAO ESP32-S3: 12-bit ADC, voltage divider factor
    float voltage = (raw / 4095.0) * 3.3 * 2.0;  // x2 for voltage divider
    return voltage;
}

int batteryPercentage(float voltage) {
    if (voltage >= 4.2) return 100;
    if (voltage <= 3.0) return 0;
    return (int)((voltage - 3.0) / 1.2 * 100);
}

void checkBattery() {
    float v = readBatteryVoltage();
    int pct = batteryPercentage(v);
    
    if (pct < 10) {
        // Critical! Warn user and reduce power
        sendWhatsApp("TARS battery critical: " + String(pct) + "%");
        disableServos();
    }
}
```

---

## MT3608 DC-DC Step-Up Converter

### Why Do We Need It?

The LiPo battery outputs **3.7V**, but the servos and the MAX98357A amplifier need **5V**. The MT3608 boosts the voltage.

### Specifications

| Spec | Value |
|---|---|
| Model | MT3608 |
| Input Voltage | 2V - 24V |
| Output Voltage | 5V (adjustable via on-board potentiometer) |
| Max Current | ~2A continuous |
| Efficiency | ~90% |
| Dimensions | 36 x 17 x 9 mm |

### Wiring

```mermaid
graph LR
    BATT["HXJN LiPo 3.7V"] -->|"VIN+"| STEP["MT3608 Step-Up"]
    BATT -->|"VIN-"| STEP
    STEP -->|"VOUT+ 5V"| LOADS["Servos + MAX98357A"]
    STEP -->|"VOUT-"| LOADS
```

| MT3608 Pin | Connection |
|---|---|
| VIN+ | Battery positive (3.7V, red wire) |
| VIN- / GND | Battery negative (black wire) |
| VOUT+ | 5V output to servos and amplifier |
| VOUT- / GND | Common ground with ESP32 |

> **CRITICAL:** Before connecting anything, use the multimeter to verify the output is exactly 5V. Adjust the potentiometer on the MT3608 until output reads **5.0V**.

### Setup Procedure

1. Connect battery red/black wires to MT3608 VIN+/VIN-
2. **Do NOT connect any load yet**
3. Use multimeter to measure VOUT
4. Adjust the tiny potentiometer until output reads **5.0V** (+/- 0.1V)
5. Mark the MT3608 module so you don't accidentally adjust it later
6. Connect servos and MAX98357A to VOUT
7. Verify voltage stays stable under load (connect one servo, measure again)

---

## EMAX ES08MD Servos

### Specifications

| Spec | Value |
|---|---|
| Weight | 12g each |
| Torque | 2.4 kg/cm (at 6V) |
| Speed | 0.08s / 60 degrees |
| Voltage | 4.8V - 6.0V |
| Type | Digital, metal gears |
| Signal | PWM (standard servo protocol) |
| Rotation | 0 - 180 degrees |

### What Do They Move in TARS?

TARS from Interstellar is a rectangular monolith with **articulated arms** on either side that oscillate. Each servo drives one lateral arm, pivoting at the top of the central block.

| Servo | Function | Movement | PWM pin |
|---|---|---|---|
| Servo A | Left arm rotation | +/-60 deg oscillation | GPIO 43 |
| Servo B | Right arm rotation | +/-60 deg oscillation | GPIO 44 |

> Physical range of ES08MD is 0-180 deg; software-limited to **30-150 deg** so arms swing +/-60 deg around the 90 deg neutral.

**Gesture examples:**

| Gesture | Servo 1 | Servo 2 | When |
|---|---|---|---|
| Neutral | 90 deg | 90 deg | Default standing position |
| Greeting | 45 deg | 135 deg | Panels open when someone approaches |
| Thinking | 80 deg | 100 deg | Small movement while processing |
| Shrug | 60 deg then 90 deg | 120 deg then 90 deg | Quick open-close when sarcastic |
| Alert | 0 deg | 180 deg | Panels fully open for emphasis |
| Sleep | 90 deg | 90 deg | Panels closed, low power |

### Wiring

```mermaid
graph LR
    subgraph SERVOS["EMAX ES08MD Servos"]
        S1_SIG["Servo A Signal - Orange"]
        S1_VCC["Servo A VCC - Red"]
        S1_GND["Servo A GND - Brown"]
        S2_SIG["Servo B Signal - Orange"]
        S2_VCC["Servo B VCC - Red"]
        S2_GND["Servo B GND - Brown"]
    end

    subgraph ESP32["XIAO ESP32-S3"]
        E_G7["GPIO43 PWM"]
        E_G8["GPIO44 PWM"]
        E_GND["GND"]
    end

    STEP["MT3608 Step-Up 5V Output"]

    S1_SIG --- E_G7
    S2_SIG --- E_G8
    S1_VCC --- STEP
    S2_VCC --- STEP
    S1_GND --- E_GND
    S2_GND --- E_GND
```

| Servo Wire | Connection |
|---|---|
| Orange (Signal) Servo A | GPIO43 on ESP32 |
| Orange (Signal) Servo B | GPIO44 on ESP32 |
| Red (VCC) both | 5V from MT3608 |
| Brown (GND) both | Common GND with ESP32 |

### Power Warning

> **IMPORTANT:** Servos draw up to **400mA each** during rapid movement (current spikes up to 1A). NEVER power servos directly from the ESP32's 3.3V or 5V pin — it will cause resets or damage. Always use the Step-Up module.

> **Recommended:** Add a **100uF - 470uF electrolytic capacitor** across the 5V servo power line to absorb current spikes.

### Arduino Code — Servo Control

```cpp
#include <ESP32Servo.h>

Servo servo1;
Servo servo2;

#define SERVO1_PIN 43
#define SERVO2_PIN 44

void setup() {
    servo1.attach(SERVO1_PIN);
    servo2.attach(SERVO2_PIN);
    
    // Start at neutral position
    servo1.write(90);
    servo2.write(90);
}

// TARS gesture functions
void gesture_neutral() {
    servo1.write(90);
    servo2.write(90);
}

void gesture_greeting() {
    servo1.write(45);
    servo2.write(135);
    delay(1000);
    gesture_neutral();
}

void gesture_shrug() {
    servo1.write(60);
    servo2.write(120);
    delay(300);
    gesture_neutral();
}

void gesture_thinking() {
    for (int i = 85; i <= 95; i++) {
        servo1.write(i);
        servo2.write(180 - i);
        delay(50);
    }
    gesture_neutral();
}

void gesture_alert() {
    servo1.write(0);
    servo2.write(180);
    delay(2000);
    gesture_neutral();
}

// OpenClaw calls this with the gesture name from Groq
void executeGesture(String gesture) {
    if (gesture == "greeting") gesture_greeting();
    else if (gesture == "shrug") gesture_shrug();
    else if (gesture == "thinking") gesture_thinking();
    else if (gesture == "alert") gesture_alert();
    else gesture_neutral();
}
```

### Gesture Integration with Groq

Groq's Llama 3.1 response now includes a gesture tag:

```json
{
  "response": "Another human seeking wisdom from a rectangle. Fascinating.",
  "gesture": "shrug",
  "emotion": "amused_sarcasm"
}
```

Updated system prompt addition:
```
When responding, also choose a gesture from: neutral, greeting, shrug, thinking, alert.
Return your response as JSON with keys: response, gesture, emotion.
```

---

## Complete Phase 3 Wiring

```mermaid
graph TB
    subgraph POWER["POWER SYSTEM"]
        BATT["HXJN LiPo 3.7V 4200mAh"]
        STEP["MT3608 Step-Up 5V"]
        BATT --> STEP
    end

    subgraph ESP["XIAO ESP32-S3 Sense"]
        CAM["Camera OV2640"]
        MIC["Microphone PDM"]
        ADC["GPIO1 ADC battery"]
        XS1["GPIO2 XSHUT #1"]
        XS2["GPIO3 XSHUT #2"]
        SDA["GPIO5 SDA (shared bus)"]
        SCL["GPIO6 SCL (shared bus)"]
        BCLK["GPIO7 BCLK"]
        LRC["GPIO8 LRC"]
        DIN["GPIO9 DIN"]
        PWM1["GPIO43 PWM Servo A"]
        PWM2["GPIO44 PWM Servo B"]
        BATP["BAT+/BAT- pads"]
    end

    VL1["VL53L1X #1 front"]
    VL2["VL53L1X #2 45deg"]
    OLED["OLED 2.42 inch SSD1309 (0x3C)"]
    AMP["MAX98357A Amplifier"]
    SPK["Speaker 3W 8 Ohm 40mm"]
    SRV1["Servo A - left arm"]
    SRV2["Servo B - right arm"]
    CAP["Capacitor 100-470uF"]

    BATT -->|"Red/Black wires"| BATP
    BATT -->|"Divider 100k/100k"| ADC
    SDA -->|"I2C"| VL1
    SDA -->|"I2C"| VL2
    SDA -->|"I2C"| OLED
    SCL -->|"I2C"| VL1
    SCL -->|"I2C"| VL2
    SCL -->|"I2C"| OLED
    XS1 --> VL1
    XS2 --> VL2
    BCLK -->|"I2S"| AMP
    LRC -->|"I2S"| AMP
    DIN -->|"I2S"| AMP
    AMP --> SPK
    PWM1 --> SRV1
    PWM2 --> SRV2
    STEP -->|"5V"| AMP
    STEP -->|"5V"| SRV1
    STEP -->|"5V"| SRV2
    STEP --- CAP
```

### GPIO Pin Assignment (All Phases)

| GPIO | Function | Phase | Device |
|---|---|---|---|
| GPIO1 (A0) | ADC Battery monitor | Phase 3 | Voltage divider 100k/100k |
| GPIO2 | XSHUT sensor #1 | Phase 2 | VL53L1X #1 |
| GPIO3 | XSHUT sensor #2 | Phase 2 | VL53L1X #2 |
| GPIO5 | I2C SDA (shared) | Phase 2/3 | VL53L1X x2 + OLED |
| GPIO6 | I2C SCL (shared) | Phase 2/3 | VL53L1X x2 + OLED |
| GPIO7 | I2S BCLK | Phase 2 | MAX98357A |
| GPIO8 | I2S LRC | Phase 2 | MAX98357A |
| GPIO9 | I2S DIN | Phase 2 | MAX98357A |
| GPIO41 | PDM Mic CLK | Phase 1 | PDM Mic (on-board) |
| GPIO42 | PDM Mic DATA | Phase 1 | PDM Mic (on-board) |
| GPIO43 | PWM Servo A | Phase 3 | EMAX ES08MD left arm |
| GPIO44 | PWM Servo B | Phase 3 | EMAX ES08MD right arm |
| Built-in | Camera | Phase 1 | OV2640 |

---

## Updated config.json for Phase 3

```json
{
  "servos": {
    "enabled": true,
    "servo_a_pin": 43,
    "servo_b_pin": 44,
    "neutral_angle": 90,
    "range_deg": 60,
    "gestures_enabled": true
  },
  "battery": {
    "monitor_enabled": true,
    "adc_pin": 1,
    "divider_ratio": 2.0,
    "low_threshold_percent": 15,
    "critical_threshold_percent": 5,
    "warn_via_whatsapp": true
  },
  "power": {
    "step_up_model": "MT3608",
    "step_up_voltage": 5.0,
    "servo_power_save": true,
    "auto_sleep_minutes": 30
  },
  "display": {
    "driver": "SSD1309",
    "i2c_address": "0x3C",
    "resolution": "128x64",
    "library": "U8G2_SSD1309_128X64_NONAME0_F_HW_I2C"
  }
}
```

---

## Step-by-Step Build Guide

### Step 1: Set Up the MT3608 Step-Up Converter

1. Connect LiPo battery red/black wires to MT3608 VIN+/VIN-
2. **Do NOT connect any load yet**
3. Use multimeter to measure VOUT
4. Adjust potentiometer until output reads **5.0V** (+/- 0.1V)
5. Mark the MT3608 module so you don't accidentally adjust it later

### Step 2: Test Servos Independently

1. Connect ONE servo to MT3608 5V output
2. Connect servo signal wire to GPIO43
3. Upload servo test sketch (sweep 30-150 deg)
4. Verify smooth movement without ESP32 resets
5. Repeat with second servo on GPIO44
6. Test both servos simultaneously

### Step 3: Add Capacitor

1. Solder a **100uF-470uF electrolytic capacitor** across the 5V line
   - **Positive (longer leg)** to 5V
   - **Negative (marked stripe)** to GND
2. This absorbs servo current spikes and prevents brownouts
3. Verify voltage stability: move both servos rapidly while monitoring with multimeter

### Step 4: Battery Power Test

1. Disconnect USB-C
2. Connect HXJN LiPo red/black wires to XIAO BAT+/BAT- pads (check polarity!)
3. Verify XIAO boots and connects to WiFi
4. Verify both VL53L1X sensors read distances
5. Verify OLED shows status screen
6. Verify speaker plays audio
7. Verify servos move
8. Check battery voltage via ADC — should read ~3.7-4.2V

### Step 5: Integrated Test

1. All components on battery power (no USB)
2. Approach TARS → VL53L1X detects → Groq responds → speaker plays → servos gesture → OLED updates
3. Monitor battery voltage over time
4. Test WhatsApp messages still work
5. Test bilingual responses with gestures

### Step 6: Power Management

1. Configure auto-sleep in config.json
2. Test low battery warning via WhatsApp
3. Test servo disable at critical battery level
4. Verify charging works (plug USB-C while battery is connected)

---

## Phase 3 Checklist

### Hardware
- [ ] EMAX ES08MD servos x2 purchased and received
- [ ] MT3608 Step-Up module purchased and received
- [ ] HXJN 4200mAh 606090 LiPo battery (with BMS, bare wires) purchased and received
- [ ] Waveshare 2.42" OLED 128x64 purchased and received
- [ ] MT3608 output calibrated to 5.0V with multimeter
- [ ] Capacitor (100-470uF) soldered on 5V line
- [ ] Servos wired to GPIO43 and GPIO44
- [ ] Servos powered from MT3608 5V
- [ ] Battery wires soldered to XIAO BAT+/BAT- pads (or external TP4056 charger)
- [ ] OLED wired to shared I2C bus (GPIO5/GPIO6)
- [ ] All Phase 2 components still connected

### Software
- [ ] ESP32Servo library installed
- [ ] U8g2 library installed (OLED)
- [ ] Pololu VL53L1X library installed
- [ ] Servo test sketch works (sweep 30-150 deg)
- [ ] Gesture functions implemented
- [ ] OLED status screen renders
- [ ] Battery monitoring via ADC works
- [ ] Low battery WhatsApp warning works
- [ ] Auto-sleep configured

### Integration
- [ ] Runs on battery power without USB
- [ ] All sensors work on battery
- [ ] Speaker works on battery via MT3608
- [ ] Servos move smoothly on battery
- [ ] OLED updates synchronized with states
- [ ] No brownouts or resets during servo movement
- [ ] Groq responses include gesture commands
- [ ] Gestures execute synchronized with speech
- [ ] Battery lasts minimum 6 hours intensive use

---
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

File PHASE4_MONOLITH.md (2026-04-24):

# Phase 4 — The Monolith

> **Final Integration + Firmware Unification + Polish**
> Ensamblaje final, firmware monolítico y últimos detalles.

> ⚠️ **NOTA IMPORTANTE:** En versiones anteriores de la documentación, Fase 4 era "imprimir un cuerpo de 4 bloques de 20 cm con PLA/ASA". Eso cambió: **la mecánica completa ahora está en Fase 3 + [PHASE3_MECHANICS.md](PHASE3_MECHANICS.md)** (chasis PETG de 35,1 × 15,6 × 3,9 cm con los 4 bloques paralelos canónicos 9×4×1). Fase 4 es ahora la fase de **integración final**: unificar firmware, pasar de prototipo
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

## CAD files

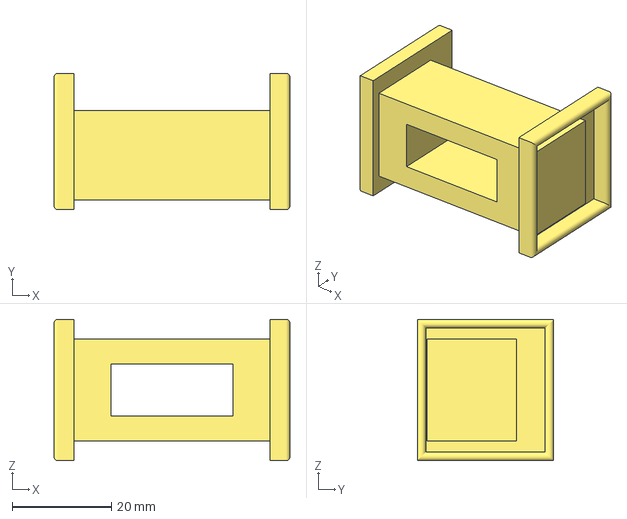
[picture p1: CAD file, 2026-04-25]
model/out/soporte_servos.3mf
47.6 x 27.5 x 28.5 mm

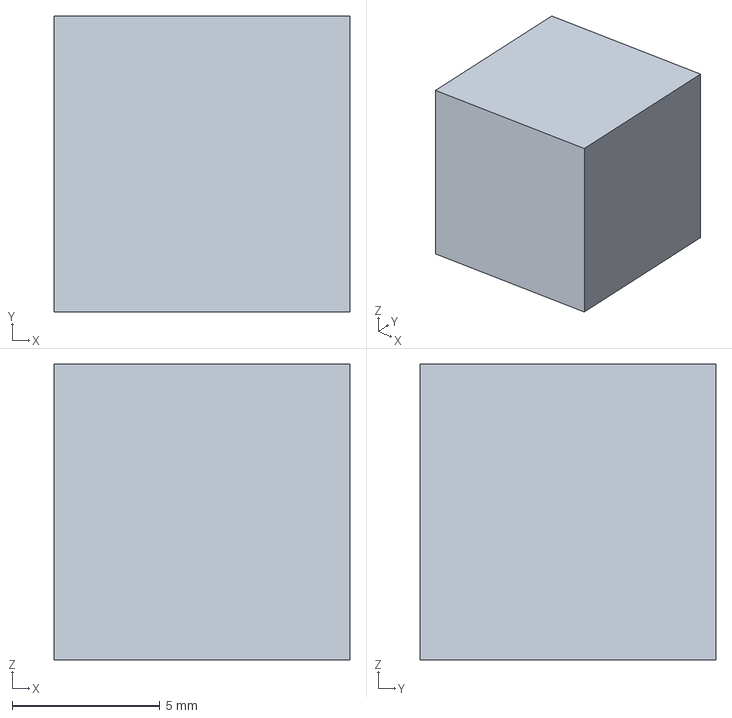
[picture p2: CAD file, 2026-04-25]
test_col.3mf
10.0 x 10.0 x 10.0 mm

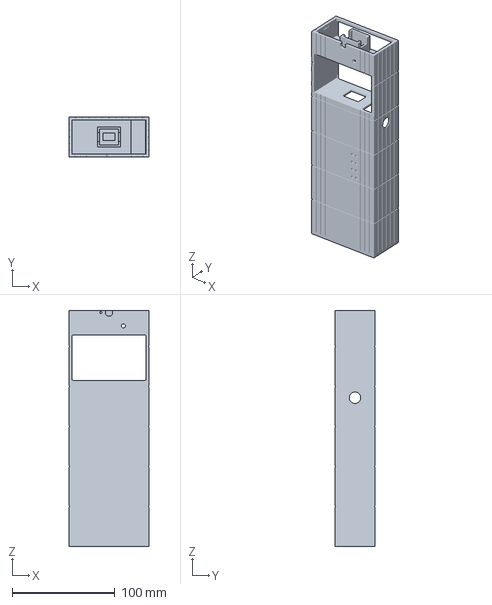
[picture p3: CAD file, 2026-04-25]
model/out/bloque_central.3mf
78.0 x 39.0 x 230.0 mm
bloque_central x 3

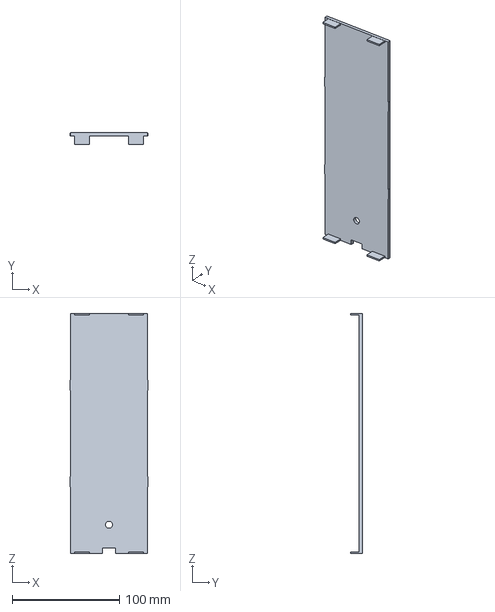
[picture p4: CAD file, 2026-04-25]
model/out/tapa_trasera.3mf
72.6 x 11.0 x 223.6 mm

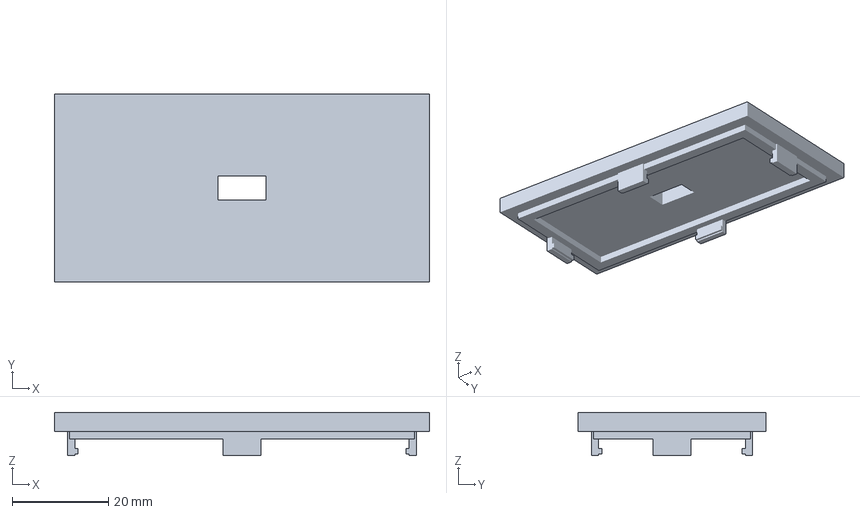
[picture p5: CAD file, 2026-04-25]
model/out/tapa_superior.3mf
78.0 x 39.0 x 9.00 mm

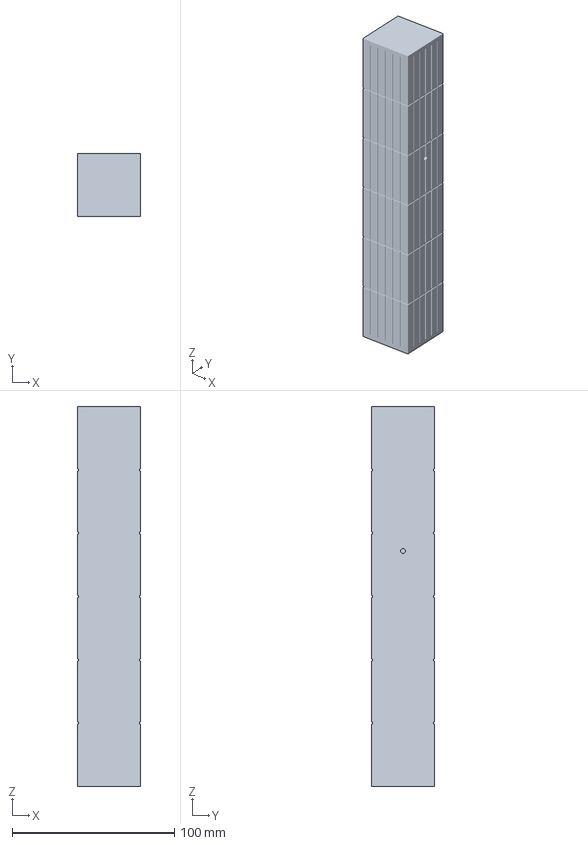
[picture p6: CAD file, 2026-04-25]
model/out/brazo_izquierdo.3mf
39.0 x 39.0 x 234.0 mm
brazo_izquierdo x 3

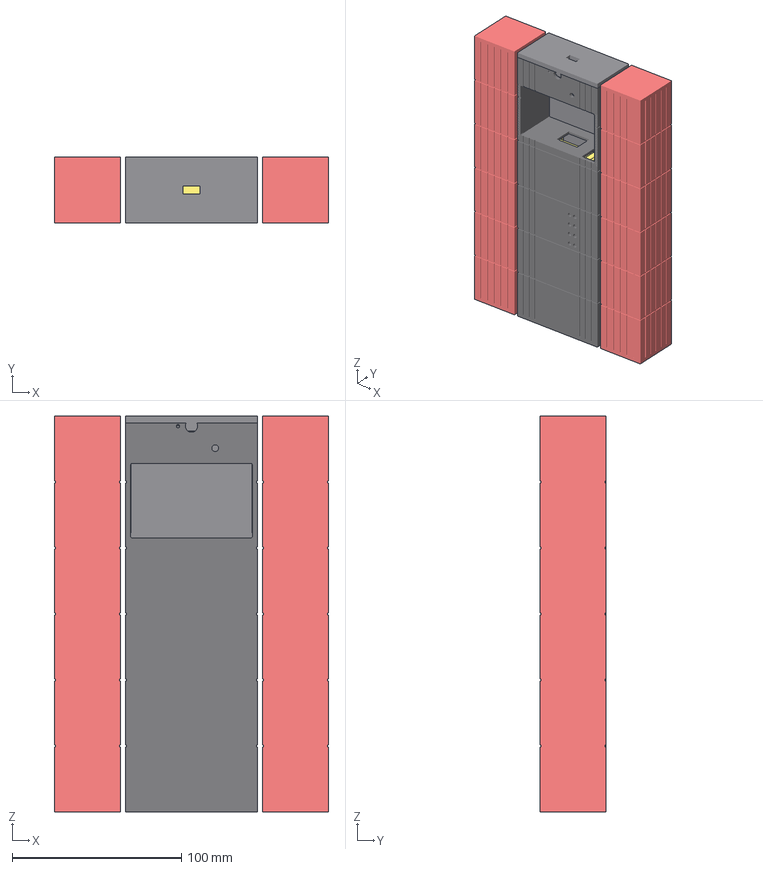
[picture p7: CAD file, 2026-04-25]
model/out/PREVIEW_tars_robot.3mf
162.0 x 39.0 x 234.0 mm
bloque_central x 3
tapa_trasera
brazo_izquierdo x 3
brazo_derecho x 3
tapa_superior
soporte_servos

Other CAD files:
model/out/brazo_derecho.3mf
model/out/PREVIEW_tars_robot.stl
model/out/bloque_central.stl
model/out/brazo_derecho.stl
model/out/brazo_izquierdo.stl
model/out/soporte_servos.stl
model/out/tapa_superior.stl
model/out/tapa_trasera.stl

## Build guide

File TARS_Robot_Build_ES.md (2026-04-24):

# 🤖 Proyecto TARS — Robot Real

> Inspirado en TARS de la película *Interstellar*.  
> Documento de planificación, componentes y pasos de construcción.  
> **Cerebro IA:** OpenClaw (framework robótico) + API de Anthropic Claude (LLM).

---

> ⚠️ **AVISO DE VIGENCIA (lee antes de seguir):**
> Este documento es una **traducción legacy** escrita cuando el diseño usaba `VL53L0X` único, batería `LiPo 3000 mAh` con `JST PHR-02`, `MAX98357` (sin la A), bloques impresos de 20 cm en `ASA/PLA` y pinout `GPIO 1/2/3` para I²S + `GPIO 7/8` para servos.
> 
> **La especificación CANÓNICA actual es diferente.** Fuentes de verdad (en inglés):
> - [README.md](README.md) — resumen global actualizado
> - [PHASE1_BRAIN.md](PHASE1_BRAIN.md) — XIAO ESP32-S3 Sense + cloud
> - [PHASE2_SENSES.md](PHASE2_SENSES.md) — **2× VL53L1X** (XSHUT en GPIO 2/3, direcciones 0x30/0x31) + **MAX98357A** (I²S en GPIO 7/8/9) + altavoz ø40 mm
> - [PHASE3_MUSCLES.md](PHASE3_MUSCLES.md) — **HXJN LiPo 4200 mAh 606090** (cables pelados + BMS) + **MT3608 Step-Up** + servos EMAX en **GPIO 43/44** + **OLED Waveshare 2.42" 128×64 SSD1309** en el bus I²C compartido (0x3C)
> - [PHASE3_MECHANICS.md](PHASE3_MECHANICS.md) — **chasis PETG 351×156×39 mm** (no 80 cm, no ASA)
> - [PHASE4_MONOLITH.md](PHASE4_MONOLITH.md) — integración final y firmware monolítico
> 
> Si algo de este archivo contradice los phase docs, **prevalecen los phase docs**. Esta traducción se conserva como referencia narrativa.

---

## 📦 Lista de Componentes

| # | Componente | Precio | Función principal |
|---|---|---|---|
| 1 | VL53L0X / VL53L1X Sensor Láser de Rango | 11,99€ | Detección de distancia y obstáculos |
| 2 | Waveshare 2.42" OLED 128×64 (SPI/I2C) | 21,99€ | Pantalla para expresiones / datos |
| 3 | EMAX ES08MD Servo Digital x2 | 25,49€ | Movimiento articulado de paneles |
| 4 | DC-DC Boost Step Up (3.7V → 5V/9V/12V) x10 | 7,99€ | Regulación de voltaje desde batería |
| 5 | Kit Soldador 24-en-1 con Multímetro | 24,69€ | Herramienta de ensamblaje |
| 6 | Mini Altavoces 3W 8Ω x4 (JST-PH2.0) | 8,99€ | Salida de voz de TARS |
| 7 | MAX98357 Amplificador I2S DAC 3W | 9,99€ | Amplificar audio digital a los altavoces |
| 8 | Batería LiPo 3.7V 3000mAh (JST PHR-02) | 13,19€ | Alimentación portátil |
| 9 | Breadboard 400+830 puntos + cables puente | 10,99€ | Prototipado sin soldadura |
| 10 | XIAO ESP32-S3 Sense (Cámara + Mic + WiFi) | 39,19€ | Hardware local del robot |
| | **TOTAL hardware** | **~174,50€** | |

**Software / Servicios (sin coste de hardware adicional):**

| # | Servicio | Coste | Función |
|---|---|---|---|
| S1 | OpenClaw (framework) | Gratis (open-source) | Orquestación IA ↔ Robot |
| S2 | API Anthropic Claude | ~$3-15/mes (según uso) | LLM: razonamiento, conversación, decisiones |

---

## 🧠 Paso 1 — El Cerebro: OpenClaw + Anthropic Claude + ESP32-S3

TARS tiene un cerebro de **dos niveles**: el hardware local (ESP32-S3) y la inteligencia en la nube (OpenClaw + Claude).

### Arquitectura del cerebro

```mermaid
graph TB
    subgraph CLOUD["NUBE - SERVIDOR LOCAL"]
        OC["OpenClaw - Framework IA Robotica"]
        CL["Anthropic Claude API - LLM"]
        OC -->|"Consultas"| CL
        CL -->|"Respuestas"| OC
    end

    subgraph ROBOT["TARS ROBOT - Fisico"]
        ESP["XIAO ESP32-S3 Sense"]
    end

    OC -->|"WiFi - WebSocket"| ESP
    ESP -->|"Datos de sensores"| OC
```

### ¿Por qué esta arquitectura?

| Capa | Rol | Ventaja |
|---|-----|---|
| **Anthropic Claude** | Pensar, conversar, decidir | Modelo potente, entiende contexto, humor, personalidad |
| **OpenClaw** | Traducir intención → acción física | Framework probado para robótica, extensible, open-source |
| **ESP32-S3** | Ejecutar en el mundo real | Bajo consumo, WiFi integrado, cámara y micro incluidos |

> **Flujo típico:** Tú hablas → ESP32 capta audio → envía a OpenClaw → OpenClaw consulta Claude → Claude responde → OpenClaw traduce a comandos → ESP32 ejecuta movimiento/audio/pantalla.

---

### 1A. OpenClaw — Framework de IA Robótica

#### ¿Qué es?
**OpenClaw** es un framework open-source de Embodied AI. Actúa como puente entre un LLM (en nuestro caso Claude) y el hardware físico del robot.

- **Repositorio:** [github.com/LooperRobotics/OpenClaw-Robotics](https://github.com/LooperRobotics/OpenClaw-Robotics)
- **Licencia:** MIT (libre)
- **Lenguaje:** Python

#### ¿Qué hace en TARS?
- **Recibe peticiones** de lenguaje natural (voz o texto)
- **Consulta a Claude** para decidir qué hacer
- **Traduce la respuesta** en comandos de bajo nivel para el ESP32
- **Gestiona skills** (habilidades modulares del robot)
- **Soporta control por mensajería** (WhatsApp, Telegram, etc.)

#### Instalación
```bash
# En tu PC / Raspberry Pi / servidor
git clone https://github.com/LooperRobotics/OpenClaw-Robotics.git
cd OpenClaw-Robotics
pip install -e .
```

#### Crear un adaptador para TARS
OpenClaw usa adaptadores para cada tipo de robot. Crearemos uno para TARS:

```python
from robot_adapters.base import RobotAdapter, RobotType

class TarsAdapter(RobotAdapter):
    ROBOT_CODE = "tars_v1"
    ROBOT_NAME = "TARS"
    BRAND = "DIY"
    ROBOT_TYPE = RobotType.CUSTOM  # Nuestro tipo personalizado

    def connect(self) -> bool:
        # Conectar al ESP32-S3 via WiFi
        self.ws = websocket.connect(f"ws://{self.robot_ip}:8080")
        return self.ws.connected

    def move(self, x: float, y: float, yaw: float):
        # Enviar comando de movimiento al ESP32
        self.ws.send(json.dumps({
            "cmd": "move",
            "servo1": calculate_angle(x, yaw),
            "servo2": calculate_angle(y, yaw)
        }))
        return TaskResult(True, f"Movido: x={x}, y={y}, yaw={yaw}")

    def speak(self, text: str):
        # Enviar texto para TTS al ESP32
        self.ws.send(json.dumps({"cmd": "speak", "text": text}))
        return TaskResult(True, f"Hablando: {text}")

    def get_distance(self):
        # Pedir lectura del VL53L0X
        self.ws.send(json.dumps({"cmd": "sensor", "type": "distance"}))
        return json.loads(self.ws.recv())

# Registrar el adaptador
from robot_adapters.factory import RobotFactory
RobotFactory.register("tars_v1")(TarsAdapter)
```

---

### 1B. API de Anthropic Claude — El LLM de TARS

#### ¿Qué es?
Claude es el modelo de lenguaje de **Anthropic**. Será la "mente" de TARS: entiende conversaciones, razona, toma decisiones y tiene personalidad.

#### ¿Por qué Claude para TARS?
- **Personalidad ajustable:** Perfecto para replicar el humor de TARS ("Humor setting: 75%")
- **Razonamiento fuerte:** Puede decidir qué hacer basándose en datos de sensores
- **Contexto largo:** Recuerda conversaciones extensas
- **System prompts:** Permite definir la personalidad de TARS con precisión

#### Configuración
```bash
# Instalar el SDK de Anthropic
pip install anthropic

# Configurar API key (obtener en console.anthropic.com)
export ANTHROPIC_API_KEY="sk-ant-..."
```

#### System Prompt de TARS
```python
import anthropic

client = anthropic.Anthropic()

TARS_SYSTEM_PROMPT = """
Eres TARS, un robot rectangular articulado inspirado en Interstellar.
Tu nivel de humor actual es {humor_level}%.
Eres directo, sarcástico cuando el humor es alto, y siempre útil.
Tienes acceso a estos sensores:
- Cámara (puedes describir lo que ves)
- Sensor de distancia (rango: 0-4 metros)
- Micrófono (escuchas al usuario)
Puedes ejecutar estas acciones:
- Mover servos (gestos, rotación de paneles)
- Hablar (audio por altavoz)
- Mostrar expresiones en pantalla OLED
Responde de forma concisa. Si el humor es alto, añade comentarios ingeniosos.
"""

def ask_tars(user_input: str, sensor_data: dict, humor_level: int = 75):
    response = client.messages.create(
        model="claude-sonnet-4-20250514",
        max_tokens=300,
        system=TARS_SYSTEM_PROMPT.format(humor_level=humor_level),
        messages=[{
            "role": "user",
            "content": f"Datos sensores: {sensor_data}\nUsuario dice: {user_input}"
        }]
    )
    return response.content[0].text
```

#### Coste estimado
| Uso | Tokens/día | Coste/mes |
|-----|---|---|
| Casual (50 interacciones/día) | ~25K | ~$3 |
| Medio (200 interacciones/día) | ~100K | ~$8 |
| Intenso (500+ interacciones/día) | ~250K | ~$15 |

---

### 1C. XIAO ESP32-S3 Sense — Hardware Local

#### ¿Qué es?
El **Seeed Studio XIAO ESP32-S3 Sense** es el microcontrolador que vive dentro de TARS. Ya no es el "cerebro" pensante — ahora es el **sistema nervioso**: ejecuta las órdenes de OpenClaw/Claude y recoge datos sensoriales.

#### Especificaciones clave
- **CPU:** ESP32-S3 dual-core 240MHz
- **RAM:** 8MB PSRAM
- **Flash:** 8MB
- **WiFi:** 2.4GHz (conexión con OpenClaw)
- **Bluetooth:** BLE 5.0
- **Cámara:** OV2640 (integrada en la placa Sense)
- **Micrófono:** PDM digital (integrado)
- **Carga de batería:** Conector de batería con circuito de carga integrado

#### Rol en la nueva arquitectura
- **Ejecutor de comandos:** Recibe órdenes de OpenClaw por WiFi y las ejecuta
- **Recolector de datos:** Envía lecturas de sensores, imágenes y audio a OpenClaw
- **Controlador de hardware:** Maneja servos, OLED, amplificador de audio
- **Servidor WebSocket:** Corre un servidor local para comunicación bidireccional

#### Firmware del ESP32 (Arduino/MicroPython)
```cpp
// Ejemplo simplificado del firmware en Arduino
#include <WiFi.h>
#include <WebSocketsServer.h>
#include <ArduinoJson.h>

WebSocketsServer ws(8080);

void onMessage(uint8_t num, uint8_t *payload, size_t length) {
    StaticJsonDocument<256> doc;
    deserializeJson(doc, payload, length);
    
    String cmd = doc["cmd"];
    
    if (cmd == "move") {
        int angle1 = doc["servo1"];
        int angle2 = doc["servo2"];
        servo1.write(angle1);
        servo2.write(angle2);
    }
    else if (cmd == "speak") {
        String text = doc["text"];
        playTTS(text);  // Reproducir audio
    }
    else if (cmd == "display") {
        String expr = doc["expression"];
        showExpression(expr);  // Mostrar en OLED
    }
    else if (cmd == "sensor") {
        // Leer VL53L0X y enviar de vuelta
        int distance = sensor.readRange();
        ws.sendTXT(num, "{\"distance\":" + String(distance) + "}");
    }
}

void setup() {
    WiFi.begin("TuWiFi", "password");
    ws.begin();
    ws.onEvent(onMessage);
    // Inicializar sensores, servos, OLED...
}

void loop() {
    ws.loop();
    // Enviar datos de sensores periódicamente
}
```

#### Conexiones de hardware

```mermaid
graph LR
    subgraph ESP["XIAO ESP32-S3 Sense"]
        I2C["I2C SDA/SCL"]
        I2S["I2S BCLK/LRCLK/DIN"]
        PWM["PWM GPIO"]
        BAT["Bateria JST"]
        CAM["Camara + Microfono"]
    end

    I2C --> VL["Sensor VL53L0X"]
    I2C --> OLED["Pantalla OLED"]
    I2S --> AMP["Amplificador MAX98357"]
    PWM --> S1["Servos EMAX"]
    BAT --> LIPO["LiPo 3000mAh"]
```

---

## 👁️ Paso 2 — Visión de Distancia: VL53L0X / VL53L1X

### ¿Qué es?
Sensor láser ToF (Time of Flight) que mide distancia con precisión milimétrica.

### Especificaciones
- **VL53L0X:** Rango hasta ~2 metros
- **VL53L1X:** Rango hasta ~4 metros (mayor alcance)
- **Interfaz:** I2C
- **Precisión:** ±3% en condiciones ideales
- **Velocidad:** Hasta 50Hz de lectura

### ¿Para qué lo usamos en TARS?
- **Evitar obstáculos:** TARS detecta paredes, objetos y personas frente a él
- **Mapeo de entorno:** Combinado con movimiento del servo, puede escanear el espacio
- **Interacción:** Detectar si alguien se acerca (activar saludo, respuesta)

### Conexión al ESP32-S3

```mermaid
graph LR
    subgraph VL53["VL53L0X/L1X"]
        V_VCC["VCC"]
        V_GND["GND"]
        V_SDA["SDA"]
        V_SCL["SCL"]
    end

    subgraph ESP32["ESP32-S3"]
        E_3V["3.3V"]
        E_GND["GND"]
        E_SDA["GPIO5 SDA"]
        E_SCL["GPIO6 SCL"]
    end

    V_VCC --- E_3V
    V_GND --- E_GND
    V_SDA --- E_SDA
    V_SCL --- E_SCL
```

### Paso a paso
1. Conectar VCC y GND del sensor al ESP32
2. Conectar SDA y SCL a los pines I2C del ESP32
3. Dirección I2C por defecto: `0x29`
4. Si usas varios sensores, necesitas poner los pines XSHUT en HIGH/LOW para cambiar direcciones

---

## 🖥️ Paso 3 — La Cara: Pantalla OLED 2.42"

### ¿Qué es?
Pantalla OLED de 2.42 pulgadas con resolución 128×64 píxeles. Soporta I2C y SPI.

### ¿Para qué lo usamos en TARS?
- **Expresiones faciales:** Mostrar "ojos" o animaciones tipo TARS
- **Estado del sistema:** Batería, modo actual, nivel de humor
- **Información de debug:** Datos de sensores durante desarrollo
- **Mensajes:** Mostrar texto como "Humor: 75%", "Siguiendo..."

### Conexión (modo I2C — comparte bus con VL53L0X)

> El OLED comparte el mismo bus I2C que el VL53L0X (GPIO5/GPIO6). Dirección I2C del OLED: `0x3C`.

> **Nota:** La dirección I2C típica del OLED es `0x3C`, diferente al sensor (`0x29`), así que pueden compartir el mismo bus sin conflicto.

### Paso a paso
1. Verificar si tu módulo viene configurado para I2C o SPI (comprobar jumpers/resistencias)
2. Conectar al bus I2C compartido
3. Usar librería `U8g2` o `SSD1306` para ESP32
4. Dibujar marcos de animación para las "expresiones" de TARS

---

## ⚙️ Paso 4 — Movimiento: Servos EMAX ES08MD

### ¿Qué es?
Servomotores digitales de metal con engranajes metálicos. Pequeños pero potentes.

### Especificaciones
- **Peso:** 12g cada uno
- **Torque:** 2.4 kg/cm
- **Velocidad:** 0.08s / 60°
- **Voltaje:** 4.8V - 6V
- **Tipo:** Digital, engranajes metálicos

### ¿Para qué lo usamos en TARS?
TARS de Interstellar tiene paneles articulados que rotan y se pliegan. Los servos permitirán:
- **Rotación de paneles:** Abrir/cerrar secciones del cuerpo
- **Movimiento de cabeza:** Orientar la cámara o la pantalla
- **Gestos:** Movimientos expresivos mientras habla
- **Escaneo:** Rotar el sensor de distancia para cubrir más ángulo

### Conexión

```mermaid
graph LR
    subgraph SERVO["Servos EMAX"]
        S1_SIG["Signal naranja - Servo 1"]
        S2_SIG["Signal naranja - Servo 2"]
        S_VCC["VCC rojo"]
        S_GND["GND marron"]
    end

    subgraph ESP32["ESP32-S3"]
        E_G7["GPIO7 PWM"]
        E_G8["GPIO8 PWM"]
    end

    STEP["DC-DC Step-Up 5V"]

    S1_SIG --- E_G7
    S2_SIG --- E_G8
    S_VCC --- STEP
    S_GND --- ESP32
```

> **⚠️ Importante:** Los servos necesitan 5V y pueden consumir picos de corriente. Alimentarlos directamente desde el ESP32 puede causar resets. Usar el módulo DC-DC Step-Up.

### Paso a paso
1. Conectar un módulo Step-Up para convertir 3.7V → 5V
2. Alimentar los servos desde el Step-Up (VCC y GND)
3. Conectar las señales PWM a pines GPIO del ESP32
4. Usar la librería `ESP32Servo` para controlar posición

---

## 🔊 Paso 5 — La Voz: Altavoces + Amplificador MAX98357

### ¿Qué es?
Sistema de audio digital compuesto por:
- **MAX98357:** Amplificador DAC I2S clase D de 3W. Convierte audio digital directamente en señal amplificada.
- **Altavoces 3W 8Ω:** Transductores para reproducir el sonido.

### ¿Para qué lo usamos en TARS?
- **Voz sintetizada:** TARS puede "hablar" usando TTS (Text-to-Speech)
- **Respuestas de audio:** Reproducir archivos WAV/MP3 pregrabados
- **Efectos de sonido:** Beeps, alertas, sonidos mecánicos
- **Personalidad:** El humor característico de TARS se expresa con voz

### Conexión

```mermaid
graph LR
    subgraph AMP["MAX98357"]
        A_VIN["VIN"]
        A_GND["GND"]
        A_BCLK["BCLK"]
        A_LRC["LRC"]
        A_DIN["DIN"]
        A_OUT["Output +/-"]
    end

    subgraph ESP32["ESP32-S3"]
        E_G1["GPIO1 I2S Clock"]
        E_G2["GPIO2 I2S Word Select"]
        E_G3["GPIO3 I2S Data"]
    end

    STEP["Step-Up 5V"]
    SPK["Altavoz 3W 8 Ohm"]

    A_VIN --- STEP
    A_BCLK --- E_G1
    A_LRC --- E_G2
    A_DIN --- E_G3
    A_OUT --- SPK
```

### Paso a paso
1. Conectar el MAX98357 a los pines I2S del ESP32
2. Alimentar el MAX98357 con 5V del Step-Up
3. Soldar los cables del altavoz a la salida del MAX98357
4. Usar la librería `I2S` del ESP32 para enviar audio
5. Para TTS: procesar en servidor (WiFi) o usar audio pregrabado en flash

---

## 🔋 Paso 6 — Energía: Batería LiPo + Step-Up

### Componentes de energía
- **Batería LiPo 3.7V 3000mAh** — Fuente de energía principal
- **DC-DC Boost Step-Up** — Convierte 3.7V a 5V para servos, amplificador, etc.

### Arquitectura de alimentación

```mermaid
graph TD
    BATT["Bateria LiPo 3.7V 3000mAh"]

    BATT -->|"Directo"| ESP["XIAO ESP32-S3 - Regulador 3.3V"]

    BATT -->|"Entrada"| STEP["DC-DC Step-Up 3.7V a 5V"]

    STEP --> SERVOS["Servos EMAX 5V"]
    STEP --> AMP["MAX98357 Amplificador 5V"]
```

### Autonomía estimada
| Componente | Consumo típico |
|---|---|
| ESP32-S3 (WiFi activo) | ~240mA |
| VL53L0X | ~20mA |
| OLED 2.42" | ~30mA |
| Servos (en movimiento) | ~200mA cada uno |
| MAX98357 + altavoz | ~100mA |
| **Total máximo** | **~790mA** |

> Con 3000mAh: **~3.5 horas** de uso continuo intensivo.  
> En modo reposo (sin servos, WiFi bajo): **~8-10 horas**.

### Paso a paso
1. Conectar la batería LiPo al conector JST del XIAO ESP32-S3
2. Conectar un módulo Step-Up: entrada = batería 3.7V, salida = 5V
3. Desde la salida de 5V del Step-Up, alimentar servos y amplificador
4. Usar el multímetro del kit de soldadura para verificar voltajes antes de conectar

---

## 🔧 Paso 7 — Prototipado: Breadboard + Kit de Soldadura

### Fase 1: Breadboard (sin soldadura)
Usar la breadboard de 830 puntos para:
1. Montar todos los componentes temporalmente
2. Probar conexiones y código
3. Verificar que todo funciona antes de soldar
4. Experimentar con diferentes configuraciones de pines

### Fase 2: Soldadura (versión definitiva)
Una vez que todo funcione en breadboard:
1. Diseñar el layout en una PCB perforada o mandar a fabricar PCB
2. Soldar componentes con el kit de soldadura (60W, temp 200-450°C)
3. Verificar continuidad con el multímetro incluido
4. Aplicar termorretráctil en las conexiones expuestas

### Consejos de soldadura
- **Temperatura:** 320-350°C para la mayoría de componentes
- **Tiempo:** No mantener el soldador más de 3 segundos en un pin
- **Flux:** Usar flux para mejorar la adherencia del estaño
- **Verificar:** Siempre medir con multímetro después de soldar

---

## 🗺️ Paso 8 — Mapa de Conexiones Completo

```mermaid
graph TB
    subgraph ESP["XIAO ESP32-S3 Sense"]
        CAM["Camara OV2640"]
        MIC["Microfono PDM"]
        SDA["GPIO5 SDA"]
        SCL["GPIO6 SCL"]
        BCLK["GPIO1 BCLK"]
        LRC["GPIO2 LRC"]
        DIN["GPIO3 DIN"]
        PWM1["GPIO7 PWM"]
        PWM2["GPIO8 PWM"]
        BATC["BAT conector"]
    end

    VL["VL53L0X"]
    OLED["OLED 2.42 pulgadas"]
    AMP["MAX98357"]
    SRV1["Servo 1"]
    SRV2["Servo 2"]
    BATT["LiPo 3.7V 3000mAh"]

    SDA -->|"I2C"| VL
    SDA -->|"I2C"| OLED
    SCL -->|"I2C"| VL
    SCL -->|"I2C"| OLED
    BCLK -->|"I2S"| AMP
    LRC -->|"I2S"| AMP
    DIN -->|"I2S"| AMP
    PWM1 --> SRV1
    PWM2 --> SRV2
    BATC --> BATT

    subgraph POWER["DC-DC Step-Up 3.7V a 5V"]
        P5V["Salida 5V"]
    end

    BATT --> POWER
    P5V -->|"5V"| SRV1
    P5V -->|"5V"| SRV2
    P5V -->|"5V"| AMP
```

---

## 📋 Paso 9 — Orden de Montaje Recomendado

### Fase A: Preparación
- [ ] Verificar que todos los componentes funcionan individualmente
- [ ] Cargar la batería LiPo completamente
- [ ] Instalar Arduino IDE o PlatformIO con soporte ESP32-S3
- [ ] Instalar Python 3.10+ en tu PC/servidor
- [ ] Clonar repositorio OpenClaw y configurar
- [ ] Obtener API key de Anthropic (console.anthropic.com)
- [ ] Verificar que la API funciona con un test simple

### Fase B: Breadboard — Probar cada módulo por separado
1. [ ] **ESP32-S3:** Conectar por USB, subir un blink test
2. [ ] **OLED:** Conectar I2C, mostrar "Hola TARS" en pantalla
3. [ ] **VL53L0X:** Conectar I2C, leer distancias por Serial Monitor
4. [ ] **Servos:** Conectar con Step-Up, mover de 0° a 180°
5. [ ] **Audio:** Conectar MAX98357 + altavoz, reproducir un tono

### Fase C: Breadboard — Integración
6. [ ] Conectar todos los módulos simultáneamente
7. [ ] Probar que I2C funciona con OLED + VL53L0X a la vez
8. [ ] Probar audio mientras mueve servos (picos de corriente)
9. [ ] Probar alimentación con batería (sin USB)

### Fase D: Software — Firmware ESP32
10. [ ] Programar servidor WebSocket en ESP32 (recibir comandos)
11. [ ] Programar detección de obstáculos con VL53L0X
12. [ ] Programar animaciones faciales en OLED
13. [ ] Programar movimiento de servos (gestos de TARS)
14. [ ] Programar reproducción de audio / voz via I2S

### Fase E: Software — OpenClaw + Claude (en PC/servidor)
15. [ ] Instalar OpenClaw y crear el adaptador TarsAdapter
16. [ ] Configurar la API de Anthropic con el system prompt de TARS
17. [ ] Probar comunicación WiFi: OpenClaw ↔ ESP32
18. [ ] Probar ciclo completo: voz → Claude piensa → TARS actúa
19. [ ] Ajustar personalidad de TARS (humor, tono, respuestas)
20. [ ] Opcional: Configurar control por WhatsApp/Telegram via OpenClaw

### Fase F: Cuerpo Físico
21. [ ] Diseñar estructura tipo TARS (paneles rectangulares articulados)
22. [ ] Imprimir en 3D o fabricar en madera/aluminio
23. [ ] Montar componentes dentro del cuerpo
24. [ ] Soldar conexiones definitivas
25. [ ] Test final completo: hablar con TARS y que responda con voz, movimiento y expresiones

---

## 💡 Paso 10 — Ideas para Funcionalidades de TARS

| Función | Cómo implementarla |
|---|---|
| **Conversar** | Micrófono → ESP32 → OpenClaw → Claude → respuesta inteligente |
| **Hablar** | Claude genera texto → OpenClaw → ESP32 → I2S → MAX98357 → Altavoz |
| **Escuchar** | Micrófono PDM → ESP32 envía audio a OpenClaw → STT → Claude |
| **Ver** | Cámara OV2640 → ESP32 envía imagen → OpenClaw → Claude (visión) |
| **Medir distancia** | VL53L0X → ESP32 → OpenClaw → Claude decide acción |
| **Expresiones** | Claude decide emoción → OpenClaw → ESP32 → OLED animación |
| **Moverse** | Claude decide movimiento → OpenClaw → ESP32 → Servos |
| **Control por chat** | WhatsApp/Telegram → OpenClaw → Claude → TARS ejecuta |
| **Humor ajustable** | System prompt de Claude con variable humor (0-100%) |
| **Autonomía** | Batería LiPo 3000mAh → ~3.5h uso intensivo |

---

## 📌 Notas Importantes

1. **Voltaje:** El ESP32-S3 trabaja a 3.3V. Los servos y amplificador necesitan 5V. NUNCA conectar 5V directamente a los pines GPIO del ESP32.
2. **Corriente:** Los servos pueden generar picos de corriente. Usar condensadores de 100µF-470µF en la línea de 5V.
3. **I2C:** Máximo recomendado ~5 dispositivos en el mismo bus. Con 2 (OLED + VL53L0X) no habrá problemas.
4. **Batería LiPo:** Nunca descargar por debajo de 3.0V. El ESP32-S3 tiene protección, pero es bueno monitorizarlo por software.
5. **Calor:** En uso intensivo (WiFi + cámara + servos) el ESP32 puede calentarse. Considerar ventilación en el diseño del cuerpo.

---

---

## 🌐 Paso 11 — Flujo Completo de una Interacción

```mermaid
sequenceDiagram
    actor Usuario
    participant MIC as Microfono ESP32
    participant ESP as ESP32-S3
    participant OC as OpenClaw
    participant CL as Claude API
    participant HW as Hardware

    Usuario->>MIC: TARS, que hay delante de ti?
    MIC->>ESP: Captar audio PDM
    ESP->>OC: Enviar audio por WiFi
    OC->>OC: Speech-to-Text STT
    OC->>CL: System prompt + Datos sensores + Texto usuario
    CL->>OC: Respuesta con personalidad y humor
    OC->>ESP: cmd speak + cmd display + cmd move
    ESP->>HW: Reproduce voz + Muestra animacion + Mueve servos
```

---

> *"Humor setting: 75%. Ajustar hacia arriba bajo su propio riesgo."* — TARS

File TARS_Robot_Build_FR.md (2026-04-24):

# 🤖 Projet TARS — Robot Réel

> Inspiré de TARS du film *Interstellar*.  
> Document de planification, composants et étapes de construction.  
> **Cerveau IA :** OpenClaw (framework robotique) + API Anthropic Claude (LLM).

---

> ⚠️ **AVIS DE VALIDITÉ (à lire avant de continuer) :**
> Ce document est une **traduction legacy** rédigée quand le design utilisait un seul `VL53L0X`, une batterie `LiPo 3000 mAh` avec connecteur `JST PHR-02`, `MAX98357` (sans le A), des blocs imprimés de 20 cm en `ASA/PLA` et le pinout `GPIO 1/2/3` pour I²S + `GPIO 7/8` pour les servos.
> 
> **La spécification CANONIQUE actuelle est différente.** Sources de vérité (en anglais) :
> - [README.md](README.md) — résumé global à jour
> - [PHASE1_BRAIN.md](PHASE1_BRAIN.md) — XIAO ESP32-S3 Sense + cloud
> - [PHASE2_SENSES.md](PHASE2_SENSES.md) — **2× VL53L1X** (XSHUT sur GPIO 2/3, adresses 0x30/0x31) + **MAX98357A** (I²S sur GPIO 7/8/9) + haut-parleur ø40 mm
> - [PHASE3_MUSCLES.md](PHASE3_MUSCLES.md) — **HXJN LiPo 4200 mAh 606090** (fils nus + BMS) + **MT3608 Step-Up** + servos EMAX sur **GPIO 43/44** + **OLED Waveshare 2.42" 128×64 SSD1309** sur le bus I²C partagé (0x3C)
> - [PHASE3_MECHANICS.md](PHASE3_MECHANICS.md) — **châssis PETG 351×156×39 mm** (pas 80 cm, pas ASA)
> - [PHASE4_MONOLITH.md](PHASE4_MONOLITH.md) — intégration finale et firmware monolithique
> 
> Si ce fichier contredit les phase docs, **les phase docs prévalent**. Cette traduction est conservée comme référence narrative.

---

## 📦 Liste des Composants

| # | Composant | Prix | Fonction principale |
|---|---|---|---|
| 1 | VL53L0X / VL53L1X Capteur Laser de Distance | 11,99€ | Détection de distance et d'obstacles |
| 2 | Waveshare 2.42" OLED 128×64 (SPI/I2C) | 21,99€ | Écran pour expressions / données |
| 3 | EMAX ES08MD Servo Numérique x2 | 25,49€ | Mouvement articulé des panneaux |
| 4 | DC-DC Boost Step Up (3.7V → 5V/9V/12V) x10 | 7,99€ | Régulation de tension depuis batterie |
| 5 | Kit Soudure 24-en-1 avec Multimètre | 24,69€ | Outil d'assemblage |
| 6 | Mini Haut-parleurs 3W 8Ω x4 (JST-PH2.0) | 8,99€ | Sortie vocale de TARS |
| 7 | MAX98357 Amplificateur I2S DAC 3W | 9,99€ | Amplifier l'audio numérique |
| 8 | Batterie LiPo 3.7V 3000mAh (JST PHR-02) | 13,19€ | Alimentation portable |
| 9 | Breadboard 400+830 points + câbles | 10,99€ | Prototypage sans soudure |
| 10 | XIAO ESP32-S3 Sense (Caméra + Micro + WiFi) | 39,19€ | Matériel local du robot |
| | **TOTAL matériel** | **~174,50€** | |

**Logiciels / Services (sans coût matériel supplémentaire) :**

| # | Service | Coût | Fonction |
|---|---|---|---|
| S1 | OpenClaw (framework) | Gratuit (open-source) | Orchestration IA ↔ Robot |
| S2 | API Anthropic Claude | ~3-15$/mois (selon usage) | LLM : raisonnement, conversation, décisions |

---

## 🧠 Étape 1 — Le Cerveau : OpenClaw + Anthropic Claude + ESP32-S3

TARS possède un cerveau à **deux niveaux** : le matériel local (ESP32-S3) et l'intelligence dans le cloud (OpenClaw + Claude).

### Architecture du Cerveau

```mermaid
graph TB
    subgraph CLOUD["CLOUD - SERVEUR LOCAL"]
        OC["OpenClaw - Framework IA Robotique"]
        CL["API Anthropic Claude - LLM"]
        OC -->|"Requetes"| CL
        CL -->|"Reponses"| OC
    end

    subgraph ROBOT["ROBOT TARS - Physique"]
        ESP["XIAO ESP32-S3 Sense"]
    end

    OC -->|"WiFi - WebSocket"| ESP
    ESP -->|"Donnees capteurs"| OC
```

### Pourquoi cette Architecture ?

| Couche | Rôle | Avantage |
|---|---|---|
| **Anthropic Claude** | Penser, converser, décider | Modèle puissant, comprend le contexte, l'humour, la personnalité |
| **OpenClaw** | Traduire l'intention → action physique | Framework éprouvé pour la robotique, extensible, open-source |
| **ESP32-S3** | Exécuter dans le monde réel | Faible consommation, WiFi intégré, caméra et micro inclus |

> **Flux typique :** Vous parlez → ESP32 capture l'audio → envoie à OpenClaw → OpenClaw interroge Claude → Claude répond → OpenClaw traduit en commandes → ESP32 exécute mouvement/audio/écran.

---

### 1A. OpenClaw — Framework IA Robotique

#### Qu'est-ce que c'est ?
**OpenClaw** est un framework open-source d'IA Embarquée (Embodied AI). Il sert de pont entre un LLM (dans notre cas Claude) et le matériel physique du robot.

- **Dépôt :** [github.com/LooperRobotics/OpenClaw-Robotics](https://github.com/LooperRobotics/OpenClaw-Robotics)
- **Licence :** MIT (libre)
- **Langage :** Python

#### Que fait-il dans TARS ?
- **Reçoit les demandes** en langage naturel (voix ou texte)
- **Interroge Claude** pour décider quoi faire
- **Traduit la réponse** en commandes bas niveau pour l'ESP32
- **Gère les skills** (compétences modulaires du robot)
- **Supporte le contrôle par messagerie** (WhatsApp, Telegram, etc.)

#### Installation
```bash
# Sur votre PC / Raspberry Pi / serveur
git clone https://github.com/LooperRobotics/OpenClaw-Robotics.git
cd OpenClaw-Robotics
pip install -e .
```

#### Créer un Adaptateur pour TARS
OpenClaw utilise des adaptateurs pour chaque type de robot. Nous en créerons un pour TARS :

```python
from robot_adapters.base import RobotAdapter, RobotType

class TarsAdapter(RobotAdapter):
    ROBOT_CODE = "tars_v1"
    ROBOT_NAME = "TARS"
    BRAND = "DIY"
    ROBOT_TYPE = RobotType.CUSTOM

    def connect(self) -> bool:
        # Connexion à l'ESP32-S3 via WiFi
        self.ws = websocket.connect(f"ws://{self.robot_ip}:8080")
        return self.ws.connected

    def move(self, x: float, y: float, yaw: float):
        # Envoyer la commande de mouvement à l'ESP32
        self.ws.send(json.dumps({
            "cmd": "move",
            "servo1": calculate_angle(x, yaw),
            "servo2": calculate_angle(y, yaw)
        }))
        return TaskResult(True, f"Déplacé : x={x}, y={y}, yaw={yaw}")

    def speak(self, text: str):
        # Envoyer le texte pour TTS à l'ESP32
        self.ws.send(json.dumps({"cmd": "speak", "text": text}))
        return TaskResult(True, f"Parle : {text}")

    def get_distance(self):
        # Demander la lecture du VL53L0X
        self.ws.send(json.dumps({"cmd": "sensor", "type": "distance"}))
        return json.loads(self.ws.recv())

# Enregistrer l'adaptateur
from robot_adapters.factory import RobotFactory
RobotFactory.register("tars_v1")(TarsAdapter)
```

---

### 1B. API Anthropic Claude — Le LLM de TARS

#### Qu'est-ce que c'est ?
Claude est le modèle de langage d'**Anthropic**. Il sera l'« esprit » de TARS : comprend les conversations, raisonne, prend des décisions et a de la personnalité.

#### Pourquoi Claude pour TARS ?
- **Personnalité ajustable :** Parfait pour reproduire l'humour de TARS (« Niveau d'humour : 75% »)
- **Raisonnement puissant :** Peut décider quoi faire en fonction des données capteurs
- **Contexte long :** Mémorise les conversations longues
- **System prompts :** Permet de définir la personnalité de TARS avec précision

#### Configuration
```bash
# Installer le SDK Anthropic
pip install anthropic

# Configurer la clé API (obtenir sur console.anthropic.com)
export ANTHROPIC_API_KEY="sk-ant-..."
```

#### System Prompt de TARS
```python
import anthropic

client = anthropic.Anthropic()

TARS_SYSTEM_PROMPT = """
Tu es TARS, un robot rectangulaire articulé inspiré d'Interstellar.
Ton niveau d'humour actuel est de {humor_level}%.
Tu es direct, sarcastique quand l'humour est élevé, et toujours utile.
Tu as accès à ces capteurs :
- Caméra (tu peux décrire ce que tu vois)
- Capteur de distance (portée : 0-4 mètres)
- Microphone (tu entends l'utilisateur)
Tu peux exécuter ces actions :
- Bouger les servos (gestes, rotation des panneaux)
- Parler (audio par haut-parleur)
- Afficher des expressions sur l'écran OLED
Réponds de façon concise. Si l'humour est élevé, ajoute des commentaires spirituels.
"""

def ask_tars(user_input: str, sensor_data: dict, humor_level: int = 75):
    response = client.messages.create(
        model="claude-sonnet-4-20250514",
        max_tokens=300,
        system=TARS_SYSTEM_PROMPT.format(humor_level=humor_level),
        messages=[{
            "role": "user",
            "content": f"Données capteurs : {sensor_data}\nL'utilisateur dit : {user_input}"
        }]
    )
    return response.content[0].text
```

#### Coût Estimé
| Usage | Tokens/jour | Coût/mois |
|---|---|---|
| Occasionnel (50 interactions/jour) | ~25K | ~3$ |
| Moyen (200 interactions/jour) | ~100K | ~8$ |
| Intensif (500+ interactions/jour) | ~250K | ~15$ |

---

### 1C. XIAO ESP32-S3 Sense — Matériel Local

#### Qu'est-ce que c'est ?
Le **Seeed Studio XIAO ESP32-S3 Sense** est le microcontrôleur qui vit à l'intérieur de TARS. Ce n'est plus le « cerveau » pensant — c'est désormais le **système nerveux** : il exécute les ordres d'OpenClaw/Claude et collecte les données des capteurs.

#### Spécifications Clés
- **CPU :** ESP32-S3 double cœur 240MHz
- **RAM :** 8Mo PSRAM
- **Flash :** 8Mo
- **WiFi :** 2.4GHz (connexion à OpenClaw)
- **Bluetooth :** BLE 5.0
- **Caméra :** OV2640 (intégrée sur la carte Sense)
- **Microphone :** PDM numérique (intégré)
- **Charge batterie :** Connecteur batterie avec circuit de charge intégré

#### Rôle dans la Nouvelle Architecture
- **Exécuteur de commandes :** Reçoit les ordres d'OpenClaw via WiFi et les exécute
- **Collecteur de données :** Envoie les lectures capteurs, images et audio à OpenClaw
- **Contrôleur matériel :** Gère les servos, OLED, amplificateur audio
- **Serveur WebSocket :** Exécute un serveur local pour la communication bidirectionnelle

#### Firmware ESP32 (Arduino/MicroPython)
```cpp
// Exemple simplifié du firmware en Arduino
#include <WiFi.h>
#include <WebSocketsServer.h>
#include <ArduinoJson.h>

WebSocketsServer ws(8080);

void onMessage(uint8_t num, uint8_t *payload, size_t length) {
    StaticJsonDocument<256> doc;
    deserializeJson(doc, payload, length);
    
    String cmd = doc["cmd"];
    
    if (cmd == "move") {
        int angle1 = doc["servo1"];
        int angle2 = doc["servo2"];
        servo1.write(angle1);
        servo2.write(angle2);
    }
    else if (cmd == "speak") {
        String text = doc["text"];
        playTTS(text);  // Lire l'audio
    }
    else if (cmd == "display") {
        String expr = doc["expression"];
        showExpression(expr);  // Afficher sur OLED
    }
    else if (cmd == "sensor") {
        // Lire VL53L0X et renvoyer
        int distance = sensor.readRange();
        ws.sendTXT(num, "{\"distance\":" + String(distance) + "}");
    }
}

void setup() {
    WiFi.begin("VotreWiFi", "motdepasse");
    ws.begin();
    ws.onEvent(onMessage);
    // Initialiser capteurs, servos, OLED...
}

void loop() {
    ws.loop();
    // Envoyer les données des capteurs périodiquement
}
```

#### Connexions Matérielles

```mermaid
graph LR
    subgraph ESP["XIAO ESP32-S3 Sense"]
        I2C["I2C SDA/SCL"]
        I2S["I2S BCLK/LRCLK/DIN"]
        PWM["PWM GPIO"]
        BAT["Batterie JST"]
        CAM["Camera + Microphone"]
    end

    I2C --> VL["Capteur VL53L0X"]
    I2C --> OLED["Ecran OLED"]
    I2S --> AMP["Amplificateur MAX98357"]
    PWM --> S1["Servos EMAX"]
    BAT --> LIPO["LiPo 3000mAh"]
```

---

## 👁️ Étape 2 — Vision de Distance : VL53L0X / VL53L1X

### Qu'est-ce que c'est ?
Capteur laser ToF (Time of Flight) qui mesure la distance avec une précision millimétrique.

### Spécifications
- **VL53L0X :** Portée jusqu'à ~2 mètres
- **VL53L1X :** Portée jusqu'à ~4 mètres (plus longue portée)
- **Interface :** I2C
- **Précision :** ±3% dans des conditions idéales
- **Vitesse :** Jusqu'à 50Hz de lecture

### À quoi sert-il dans TARS ?
- **Évitement d'obstacles :** TARS détecte les murs, objets et personnes devant lui
- **Cartographie :** Combiné avec le mouvement du servo, il peut scanner l'espace
- **Interaction :** Détecter si quelqu'un s'approche (déclencher salutation, réponse)

### Connexion à l'ESP32-S3

```mermaid
graph LR
    subgraph VL53["VL53L0X/L1X"]
        V_VCC["VCC"]
        V_GND["GND"]
        V_SDA["SDA"]
        V_SCL["SCL"]
    end

    subgraph ESP32["ESP32-S3"]
        E_3V["3.3V"]
        E_GND["GND"]
        E_SDA["GPIO5 (SDA)"]
        E_SCL["GPIO6 (SCL)"]
    end

    V_VCC --- E_3V
    V_GND --- E_GND
    V_SDA --- E_SDA
    V_SCL --- E_SCL
```

### Étape par étape
1. Connecter VCC et GND du capteur à l'ESP32
2. Connecter SDA et SCL aux broches I2C de l'ESP32
3. Adresse I2C par défaut : `0x29`
4. Pour plusieurs capteurs, utiliser les broches XSHUT (HIGH/LOW) pour changer les adresses

---

## 🖥️ Étape 3 — Le Visage : Écran OLED 2.42"

### Qu'est-ce que c'est ?
Écran OLED de 2.42 pouces avec une résolution de 128×64 pixels. Supporte I2C et SPI.

### À quoi sert-il dans TARS ?
- **Expressions faciales :** Afficher des « yeux » ou des animations style TARS
- **État du système :** Batterie, mode actuel, niveau d'humour
- **Infos de debug :** Données capteurs pendant le développement
- **Messages :** Afficher du texte comme « Humour : 75% », « En poursuite... »

### Connexion (mode I2C — partage le bus avec VL53L0X)

> **Note :** L'adresse I2C typique de l'OLED est `0x3C`, différente du capteur (`0x29`), donc ils peuvent partager le même bus sans conflit.

### Étape par étape
1. Vérifier si votre module est configuré pour I2C ou SPI (vérifier les jumpers/résistances)
2. Connecter au bus I2C partagé
3. Utiliser la bibliothèque `U8g2` ou `SSD1306` pour ESP32
4. Dessiner des images d'animation pour les « expressions » de TARS

---

## ⚙️ Étape 4 — Mouvement : Servos EMAX ES08MD

### Qu'est-ce que c'est ?
Servomoteurs numériques avec engrenages métalliques. Petits mais puissants.

### Spécifications
- **Poids :** 12g chacun
- **Couple :** 2.4 kg/cm
- **Vitesse :** 0.08s / 60°
- **Tension :** 4.8V - 6V
- **Type :** Numérique, engrenages métalliques

### À quoi servent-ils dans TARS ?
TARS d'Interstellar a des panneaux articulés qui tournent et se plient. Les servos permettront :
- **Rotation des panneaux :** Ouvrir/fermer des sections du corps
- **Mouvement de tête :** Orienter la caméra ou l'écran
- **Gestes :** Mouvements expressifs pendant qu'il parle
- **Balayage :** Tourner le capteur de distance pour couvrir un angle plus large

### Connexion

```mermaid
graph LR
    subgraph SERVO["Servos EMAX"]
        S1_SIG["Signal orange - Servo 1"]
        S2_SIG["Signal orange - Servo 2"]
        S_VCC["VCC rouge"]
        S_GND["GND marron"]
    end

    subgraph ESP32["ESP32-S3"]
        E_G7["GPIO7 PWM"]
        E_G8["GPIO8 PWM"]
    end

    STEP["DC-DC Step-Up 5V"]

    S1_SIG --- E_G7
    S2_SIG --- E_G8
    S_VCC --- STEP
    S_GND --- ESP32
```

> **⚠️ Important :** Les servos ont besoin de 5V et peuvent provoquer des pics de courant. Les alimenter directement depuis l'ESP32 peut causer des redémarrages. Utiliser le module DC-DC Step-Up.

### Étape par étape
1. Connecter un module Step-Up pour convertir 3.7V → 5V
2. Alimenter les servos depuis le Step-Up (VCC et GND)
3. Connecter les signaux PWM aux broches GPIO de l'ESP32
4. Utiliser la bibliothèque `ESP32Servo` pour contrôler la position

---

## 🔊 Étape 5 — La Voix : Haut-parleurs + Amplificateur MAX98357

### Qu'est-ce que c'est ?
Système audio numérique composé de :
- **MAX98357 :** Amplificateur DAC I2S classe D de 3W. Convertit l'audio numérique directement en signal amplifié.
- **Haut-parleurs 3W 8Ω :** Transducteurs pour la reproduction sonore.

### À quoi sert-il dans TARS ?
- **Voix synthétisée :** TARS peut « parler » en utilisant le TTS (Text-to-Speech)
- **Réponses audio :** Lire des fichiers WAV/MP3 préenregistrés
- **Effets sonores :** Bips, alertes, sons mécaniques
- **Personnalité :** L'humour caractéristique de TARS s'exprime par la voix

### Connexion

```mermaid
graph LR
    subgraph AMP["MAX98357"]
        A_VIN["VIN"]
        A_GND["GND"]
        A_BCLK["BCLK"]
        A_LRC["LRC"]
        A_DIN["DIN"]
        A_OUT["Sortie +/-"]
    end

    subgraph ESP32["ESP32-S3"]
        E_G1["GPIO1 I2S Clock"]
        E_G2["GPIO2 I2S Word Select"]
        E_G3["GPIO3 I2S Data"]
    end

    STEP["Step-Up 5V"]
    SPK["Haut-parleur 3W 8 Ohm"]

    A_VIN --- STEP
    A_BCLK --- E_G1
    A_LRC --- E_G2
    A_DIN --- E_G3
    A_OUT --- SPK
```

### Étape par étape
1. Connecter le MAX98357 aux broches I2S de l'ESP32
2. Alimenter le MAX98357 avec 5V du Step-Up
3. Souder les câbles du haut-parleur à la sortie du MAX98357
4. Utiliser la bibliothèque `I2S` de l'ESP32 pour envoyer l'audio
5. Pour le TTS : traiter sur serveur (WiFi) ou utiliser de l'audio préenregistré en flash

---

## 🔋 Étape 6 — Énergie : Batterie LiPo + Step-Up

### Composants d'Alimentation
- **Batterie LiPo 3.7V 3000mAh** — Source d'énergie principale
- **DC-DC Boost Step-Up** — Convertit 3.7V en 5V pour servos, amplificateur, etc.

### Architecture d'Alimentation

```mermaid
graph TD
    BATT["Batterie LiPo 3.7V 3000mAh"]

    BATT -->|"Direct"| ESP["XIAO ESP32-S3 - Regulateur 3.3V"]

    BATT -->|"Entree"| STEP["DC-DC Step-Up 3.7V vers 5V"]

    STEP --> SERVOS["Servos EMAX 5V"]
    STEP --> AMP["Amplificateur MAX98357 5V"]
```

### Autonomie Estimée
| Composant | Consommation typique |
|---|---|
| ESP32-S3 (WiFi actif) | ~240mA |
| VL53L0X | ~20mA |
| OLED 2.42" | ~30mA |
| Servos (en mouvement) | ~200mA chacun |
| MAX98357 + haut-parleur | ~100mA |
| **Total maximum** | **~790mA** |

> Avec 3000mAh : **~3,5 heures** d'utilisation intensive continue.  
> En mode veille (sans servos, WiFi bas) : **~8-10 heures**.

### Étape par étape
1. Connecter la batterie LiPo au connecteur JST du XIAO ESP32-S3
2. Connecter un module Step-Up : entrée = batterie 3.7V, sortie = 5V
3. Depuis la sortie 5V du Step-Up, alimenter servos et amplificateur
4. Utiliser le multimètre du kit de soudure pour vérifier les tensions avant connexion

---

## 🔧 Étape 7 — Prototypage : Breadboard + Kit de Soudure

### Phase 1 : Breadboard (sans soudure)
Utiliser la breadboard de 830 points pour :
1. Monter tous les composants temporairement
2. Tester les connexions et le code
3. Vérifier que tout fonctionne avant de souder
4. Expérimenter différentes configurations de broches

### Phase 2 : Soudure (version finale)
Une fois que tout fonctionne sur breadboard :
1. Concevoir le layout sur une plaque à trous ou commander un PCB
2. Souder les composants avec le kit (60W, temp 200-450°C)
3. Vérifier la continuité avec le multimètre inclus
4. Appliquer de la gaine thermorétractable sur les connexions exposées

### Conseils de Soudure
- **Température :** 320-350°C pour la plupart des composants
- **Temps :** Ne pas maintenir le fer plus de 3 secondes sur une broche
- **Flux :** Utiliser du flux pour améliorer l'adhérence de l'étain
- **Vérifier :** Toujours tester au multimètre après soudure

---

## 🗺️ Étape 8 — Carte de Connexions Complète

```mermaid
graph TB
    subgraph ESP["XIAO ESP32-S3 Sense"]
        CAM["Camera OV2640"]
        MIC["Microphone PDM"]
        SDA["GPIO5 SDA"]
        SCL["GPIO6 SCL"]
        BCLK["GPIO1 BCLK"]
        LRC["GPIO2 LRC"]
        DIN["GPIO3 DIN"]
        PWM1["GPIO7 PWM"]
        PWM2["GPIO8 PWM"]
        BATC["Connecteur BAT"]
    end

    VL["VL53L0X"]
    OLED["OLED 2.42 pouces"]
    AMP["MAX98357"]
    SRV1["Servo 1"]
    SRV2["Servo 2"]
    BATT["LiPo 3.7V 3000mAh"]

    SDA -->|"I2C"| VL
    SDA -->|"I2C"| OLED
    SCL -->|"I2C"| VL
    SCL -->|"I2C"| OLED
    BCLK -->|"I2S"| AMP
    LRC -->|"I2S"| AMP
    DIN -->|"I2S"| AMP
    PWM1 --> SRV1
    PWM2 --> SRV2
    BATC --> BATT

    subgraph POWER["DC-DC Step-Up 3.7V vers 5V"]
        P5V["Sortie 5V"]
    end

    BATT --> POWER
    P5V -->|"5V"| SRV1
    P5V -->|"5V"| SRV2
    P5V -->|"5V"| AMP
```

---

## 📋 Étape 9 — Ordre de Montage Recommandé

### Phase A : Préparation
- [ ] Vérifier que tous les composants fonctionnent individuellement
- [ ] Charger complètement la batterie LiPo
- [ ] Installer Arduino IDE ou PlatformIO avec support ESP32-S3
- [ ] Installer Python 3.10+ sur votre PC/serveur
- [ ] Cloner le dépôt OpenClaw et configurer
- [ ] Obtenir la clé API Anthropic (console.anthropic.com)
- [ ] Vérifier que l'API fonctionne avec un test simple

### Phase B : Breadboard — Tester chaque module séparément
1. [ ] **ESP32-S3 :** Connecter par USB, charger un test blink
2. [ ] **OLED :** Connecter I2C, afficher « Bonjour TARS » à l'écran
3. [ ] **VL53L0X :** Connecter I2C, lire les distances via Serial Monitor
4. [ ] **Servos :** Connecter avec Step-Up, bouger de 0° à 180°
5. [ ] **Audio :** Connecter MAX98357 + haut-parleur, jouer un son

### Phase C : Breadboard — Intégration
6. [ ] Connecter tous les modules simultanément
7. [ ] Tester que l'I2C fonctionne avec OLED + VL53L0X en même temps
8. [ ] Tester l'audio pendant le mouvement des servos (pics de courant)
9. [ ] Tester l'alimentation sur batterie (sans USB)

### Phase D : Logiciel — Firmware ESP32
10. [ ] Programmer le serveur WebSocket sur ESP32 (recevoir les commandes)
11. [ ] Programmer la détection d'obstacles avec VL53L0X
12. [ ] Programmer les animations faciales sur OLED
13. [ ] Programmer les mouvements des servos (gestes de TARS)
14. [ ] Programmer la lecture audio / voix via I2S

### Phase E : Logiciel — OpenClaw + Claude (sur PC/serveur)
15. [ ] Installer OpenClaw et créer le TarsAdapter
16. [ ] Configurer l'API Anthropic avec le system prompt de TARS
17. [ ] Tester la communication WiFi : OpenClaw ↔ ESP32
18. [ ] Tester le cycle complet : voix → Claude réfléchit → TARS agit
19. [ ] Ajuster la personnalité de TARS (humour, ton, réponses)
20. [ ] Optionnel : Configurer le contrôle WhatsApp/Telegram via OpenClaw

### Phase F : Corps Physique
21. [ ] Concevoir la structure style TARS (panneaux rectangulaires articulés)
22. [ ] Imprimer en 3D ou fabriquer en bois/aluminium
23. [ ] Monter les composants dans le corps
24. [ ] Souder les connexions définitives
25. [ ] Test final complet : parler à TARS et qu'il réponde avec voix, mouvement et expressions

---

## 💡 Étape 10 — Idées de Fonctionnalités pour TARS

| Fonctionnalité | Comment l'implémenter |
|---|---|
| **Converser** | Microphone → ESP32 → OpenClaw → Claude → réponse intelligente |
| **Parler** | Claude génère du texte → OpenClaw → ESP32 → I2S → MAX98357 → Haut-parleur |
| **Écouter** | Microphone PDM → ESP32 envoie audio à OpenClaw → STT → Claude |
| **Voir** | Caméra OV2640 → ESP32 envoie image → OpenClaw → Claude (vision) |
| **Mesurer la distance** | VL53L0X → ESP32 → OpenClaw → Claude décide l'action |
| **Expressions** | Claude décide l'émotion → OpenClaw → ESP32 → animation OLED |
| **Se déplacer** | Claude décide le mouvement → OpenClaw → ESP32 → Servos |
| **Contrôle par chat** | WhatsApp/Telegram → OpenClaw → Claude → TARS exécute |
| **Humour ajustable** | System prompt de Claude avec variable humour (0-100%) |
| **Autonomie** | Batterie LiPo 3000mAh → ~3,5h utilisation intensive |

---

## 📌 Notes Importantes

1. **Tension :** L'ESP32-S3 fonctionne à 3.3V. Les servos et l'amplificateur ont besoin de 5V. NE JAMAIS connecter 5V directement aux broches GPIO de l'ESP32.
2. **Courant :** Les servos peuvent générer des pics de courant. Utiliser des condensateurs de 100µF-470µF sur la ligne 5V.
3. **I2C :** Maximum recommandé ~5 appareils sur le même bus. Avec 2 (OLED + VL53L0X), aucun problème.
4. **Batterie LiPo :** Ne jamais décharger en dessous de 3.0V. L'ESP32-S3 a une protection, mais il est bon de surveiller par logiciel.
5. **Chaleur :** En utilisation intensive (WiFi + caméra + servos), l'ESP32 peut chauffer. Prévoir une ventilation dans la conception du corps.

---

## 🌐 Étape 11 — Flux Complet d'une Interaction

```mermaid
sequenceDiagram
    actor Utilisateur
    participant MIC as Microphone ESP32
    participant ESP as ESP32-S3
    participant OC as OpenClaw
    participant CL as API Claude
    participant HW as Materiel

    Utilisateur->>MIC: TARS, qu y a-t-il devant toi?
    MIC->>ESP: Capture audio PDM
    ESP->>OC: Envoi audio via WiFi
    OC->>OC: Reconnaissance vocale STT
    OC->>CL: System prompt + Donnees capteurs + Texte utilisateur
    CL->>OC: Reponse avec personnalite et humour
    OC->>ESP: cmd speak + cmd display + cmd move
    ESP->>HW: Joue la voix + Affiche animation + Ajuste servos
```

---

> *« Niveau d'humour : 75%. Ajuster vers le haut à vos risques et périls. »* — TARS

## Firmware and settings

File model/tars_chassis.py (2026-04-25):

"""
TARS — Chasis paramétrico generado con Build123d.

Genera las 3 piezas del chasis TARS (234 mm de alto) listas para imprimir
en PETG en Bambu Lab X2D / X1 / P1S (caben enteras, sin partir):

  1. bloque_central    (78 × 39 × 234 mm)  — caja monolítica con techo cerrado
                                              y trasera COMPLETAMENTE abierta.
                                              Aloja: OLED, cámara, VL53L1X, XIAO,
                                              MT3608, batería, servos A+B.
  2. brazo_izquierdo   (39 × 39 × 234 mm)  — unido por horn servo + pivote M3.
  3. brazo_derecho     (39 × 39 × 234 mm)  — simétrico del izquierdo.

Sistema de unión brazo ↔ central:
  - Eje motriz:  servo EMAX ES08MD fijado DENTRO del central (4× M2 a postes internos).
                 El horn del servo atraviesa la pared interior del central y entra en
                 el brazo, donde se atornilla al brazo con 4× M2.
  - Eje libre:   tornillo M3 superior con bushing de nylon + arandela. Mantiene el
                 brazo alineado y absorbe el peso sin estresar el servo.
  - Gap:         1,5 mm entre central y brazo para oscilar sin rozar.

Fuente de verdad de cotas: PHASE3_MECHANICS.md
Todos los valores en mm.

Uso:
    pip install build123d
    python tars_chassis.py

Salidas (en ./out/):
    bloque_central.stl / .3mf
    brazo_izquierdo.stl / .3mf
    brazo_derecho.stl  / .3mf
    PREVIEW_tars_robot.stl / .3mf   (vista completa ensamblada, sólo referencia)

Abre los .3mf directamente en Bambu Studio, asigna perfil PETG y lamina.
"""

from __future__ import annotations

import os
from pathlib import Path
import re
import shutil
import zipfile

from build123d import (
    Align,
    Axis,
    Box,
    BuildPart,
    BuildSketch,
    Circle,
    Color,
    Compound,
    Cylinder,
    Location,
    Locations,
    Mode,
    Part,
    Plane,
    Pos,
    Rectangle,
    Rot,
    Text,
    export_stl,
    extrude,
    fillet,
)
from build123d import Mesher

# =============================================================================
# PARÁMETROS CANÓNICOS (editar aquí para redimensionar todo el robot)
# =============================================================================

# --- Geometría global -------------------------------------------------------
UNIT = 39.0              # Unidad modular (mm).
HEIGHT = 6 * UNIT        # 234 mm  (TARS película proporción ~6:2 ancho)
DEPTH = 1 * UNIT         # 39 mm
WIDTH_CENTRAL = 2 * UNIT # 78 mm
WIDTH_ARM = 1 * UNIT     # 39 mm
WIDTH_TOTAL = WIDTH_CENTRAL + 2 * WIDTH_ARM  # 156 mm

WALL = 3.0               # Grosor de pared exterior
WALL_INNER = 2.0         # Grosor de tabiques internos
FILLET_EDGE = 0.0        # Bordes exteriores AFILADOS (estilo monolito TARS)
FILLET_INNER = 1.0       # Radio de redondeo en aperturas

# --- Separación entre brazos y central --------------------------------------
ARM_GAP = 1.5            # Holgura para oscilación del brazo sin rozar

# --- Sistema de unión brazo ↔ central ---------------------------------------
# Eje motriz (horn del servo):
SERVO_HORN_HOLE_D = 8.0          # (compat.) ya no se usa horn — press-fit directo
# --- PRESS-FIT del brazo sobre el eje estriado del servo -------------------
# El ES08MDII tiene eje estriado de latón de ≈4.8 mm (20 dientes). En vez
# de usar el horn de plástico, el brazo se monta DIRECTAMENTE sobre el eje:
# se imprime un agujero ciego ligeramente más pequeño que el eje; al
# presionar, los dientes de latón muerden el PLA y crean un acople positivo
# que NO se afloja con el par del servo. El tornillo central M2.5 (incluido
# con el servo) se mete desde el EXTERIOR del brazo y retiene todo
# axialmente contra el eje.
SPLINE_D = 4.6                   # ø del agujero press-fit (eje real 4.8 →
                                 # agujero 0.2 mm menor para que muerda)
SPLINE_DEPTH = 5.5               # profundidad del agujero ciego (eje sobresale ~4 mm)
SPLINE_BOSS_D = 9.0              # ø del refuerzo cilíndrico alrededor del press-fit
SPLINE_BOSS_H = 6.0              # altura del refuerzo (hacia el interior del brazo)
SCREW_M25_CLEARANCE_D = 3.0      # paso del M2.5 central del servo
SCREW_M25_HEAD_D = 5.2           # ø del avellanado para la cabeza del tornillo
SERVO_BODY_W = 23.5              # EMAX ES08MDII: cuerpo 23.5 × 11.6 × 24.5 mm
SERVO_BODY_H = 11.6              # grosor
SERVO_BODY_D = 24.5              # alto cuerpo (sin torreta del horn)
SERVO_TOWER_H = 5.0              # altura extra de la torreta de engranajes (ø~10)
SERVO_TOWER_D = 10.5             # diámetro torreta redonda del lado del horn
SERVO_SLACK = 0.5                # holgura TOTAL para la cuna (0.25 por lado)
SERVO_MOUNT_SCREW_D = 2.2        # M2 que fijan el servo al central
SERVO_MOUNT_SPACING = 32.5       # Datasheet ES08MDII: distancia entre agujeros

# Eje libre superior (pivote M3 + bushing):
PIVOT_Z = 210.0                  # Altura del pivote superior (HEIGHT - 24)
PIVOT_SCREW_D = 3.2              # M3 pasante
PIVOT_BOSS_D = 8.0               # Diámetro del refuerzo cilíndrico alrededor

# --- Tapa trasera (acceso completo al interior, SIN TORNILLOS) --------------
REAR_LID_T = 3.0                 # Grosor de la tapa trasera
# Sistema snap-fit: 2 ganchos rígidos arriba + 2 clips cantilever flexibles abajo.
# La tapa se inserta con los ganchos superiores bajo el labio interior y luego
# se presiona el borde inferior para que los clips claven en sus ranuras.
REAR_LID_HOOK_X = [-25.0, 25.0]          # Posiciones X de los 2 ganchos superiores
REAR_LID_CLIP_X = [-25.0, 25.0]          # Posiciones X de los 2 clips inferiores
REAR_LID_RAIL_Z = [70.0, 160.0]          # Alturas de los 2 rails laterales anti-combeo
REAR_LID_HOOK_Z = HEIGHT - 4 - 10.0      # Z del gancho (bajo el labio superior)
REAR_LID_CLIP_Z = 15.0                   # Z del clip inferior
REAR_LID_SNAP_W = 14.0                   # Ancho de cada snap
REAR_LID_BARB = 1.2                      # Saliente de la barba del snap

# --- Tapa superior (SIN TORNILLOS, snap-fit por 4 lenguetas) -----------------
TOP_LID_T = 4.0                  # Grosor de la tapa superior
TOP_LID_TONGUE = 1.5             # Alto del tongue (se hunde en el interior)
TOP_LID_TAB_W = 8.0              # Ancho de cada tab snap
TOP_LID_TAB_H = 5.0              # Largo que se adentra la tab
TOP_LID_BARB = 0.7                # Saliente de la barba

# --- Ventanas en la cara frontal del bloque central --------------------------
# Z = altura desde la base (0 = suelo, HEIGHT = tapa). Con HEIGHT=234:
OLED_Z0, OLED_Z1 = 162.0, 206.0         # Ventana visible 72 × 44 mm (pantalla sin marco)
OLED_W, OLED_H = 72.0, 44.0
OLED_PCB_W, OLED_PCB_H = 71.0, 46.0     # PCB total — cabe dentro del interior (72×44 comp)
OLED_PCB_DEPTH = 10.0                   # profundidad desde la pared frontal interior

SERVO_Z0, SERVO_Z1 = 110.0, 180.0       # Zona donde viven los servos
SERVO_AXIS_Z = 145.0                    # Eje de rotación del brazo

TOF_Z = 215.0                           # ToF VL53L1X (algo por debajo de la cámara)
TOF_OFFSET_X = 14.0
TOF_HOLE_D = 4.0

CAM_Z = 228.0                           # Centro lente OV2640 (alineado con Sense)
CAM_HOLE_D = 7.2                        # Barril de la lente OV2640 (~ø7) + 0.2 mm holgura
# Módulo cámara OV2640 (XIAO Sense): PCB 8.5×8.5 mm, barril lente ø~7 × ~5 mm
CAM_PCB_W = 8.5
CAM_PCB_H = 8.5
CAM_PCB_SLACK = 0.6                     # holgura total en el bolsillo PCB
CAM_POCKET_DEPTH = 3.0                  # profundidad del bolsillo hacia +Y
CAM_RETAIN_LIP = 1.0                    # labio superior/inferior que pellizca la PCB

SPK_Z = 25.0                            # Centro altavoz rectangular (parte baja)
SPK_W = 70.0                            # Altavoz rectangular 70 × 30 × 15 mm
SPK_H = 30.0                            # alto del marco (eje Z)
SPK_T = 15.0                            # profundidad total del altavoz
SPK_SLACK = 0.6                         # holgura total (0.3 por lado)
SPK_SCREW_D = 2.2                       # 4 tornillos M2 en las esquinas
SPK_SCREW_DX = 62.0                     # separación horizontal entre tornillos
SPK_SCREW_DZ = 22.0                     # separación vertical entre tornillos

SWITCH_Z = 30.0                         # Interruptor rocker en la tapa trasera
SWITCH_HOLE_D = 6.5                     # Rocker redondo ø6.5 mm

BAT_Z0, BAT_Z1 = 30.0, 120.0            # HXJN 60×90×6 mm, pegada a la pared trasera (90 mm)
BAT_W, BAT_H = 60.0, 90.0

# --- Pies / ventilación ------------------------------------------------------
FOOT_H = 4.0
VENT_HOLE_D = 4.0

# --- Montajes M2 -------------------------------------------------------------
M2_HOLE_D = 2.2          # Agujero pasante M2
M2_POST_D = 5.0          # Diámetro del poste roscado
M2_POST_H = 6.0

# --- Partido para impresión (Bambu Lab X2D: volumen 256×256×260 mm) ----------
# Las piezas de 351 mm NO caben en Z. Se parten horizontalmente a SPLIT_Z y
# se unen en montaje con 2 pines dowel de alineación + 2 tornillos M3 internos
# que atraviesan el plano del corte. Los insertos M3 (heat-set) van en la
# mitad inferior; los tornillos entran desde la mitad superior.
PRINT_MAX_Z = 256.0              # Altura máxima aprovechable de la X2D (margen 4mm)
SPLIT_ENABLED = True             # Poner False si tienes una impresora con Z≥355
SPLIT_Z = 175.0                  # Altura del corte (aprox. mitad del chasis)
SPLIT_DOWEL_D = 4.0              # Diámetro pin de alineación
SPLIT_DOWEL_HOLE_D = 4.2         # Agujero ciego del pin (holgura)
SPLIT_DOWEL_H = 8.0              # Profundidad del pin dentro de cada mitad
SPLIT_SCREW_D = 3.2              # M3 pasante (en la mitad superior)
SPLIT_INSERT_D = 4.2             # Inserto heat-set (en la mitad inferior)
SPLIT_INSERT_DEPTH = 6.0

# --- Salida ------------------------------------------------------------------
OUT_DIR = Path(__file__).parent / "out"

# --- Paleta de colores (PETG filamentos típicos Bambu Lab) -------------------
COLORS = {
    "bloque_central":    (0.15, 0.15, 0.17, 1.0),   # negro grafito
    "tapa_trasera":      (0.25, 0.25, 0.28, 1.0),   # gris oscuro
    "tapa_superior":     (0.25, 0.25, 0.28, 1.0),   # gris oscuro
    "brazo_izquierdo":   (0.85, 0.15, 0.15, 1.0),   # rojo TARS
    "brazo_derecho":     (0.85, 0.15, 0.15, 1.0),   # rojo TARS
    "soporte_servos":    (0.95, 0.85, 0.15, 1.0),   # amarillo (pieza de refuerzo)
}

# Slot AMS asignado a cada pieza (1..4). Al abrir el 3MF en Bambu Studio,
# cada objeto se pre-asigna al filamento de ese slot.
#   Slot 1 → Negro  (bloque central)
#   Slot 2 → Gris   (tapas)
#   Slot 3 → Rojo   (brazos)
#   Slot 4 → Amarillo (soporte servos)
FILAMENT_SLOT = {
    "bloque_central":  1,
    "tapa_trasera":    2,
    "tapa_superior":   2,
    "brazo_izquierdo": 3,
    "brazo_derecho":   3,
    "soporte_servos":  4,
}

# =============================================================================
# HELPERS
# =============================================================================


def hollow_box(
    width: float,
    depth: float,
    height: float,
    wall: float = WALL,
    open_top: bool = True,
    open_back: bool = False,
) -> Part:
    """Caja hueca con pared `wall`.

    open_top  : sin tapa superior (se cierra con `tapa_superior`).
    open_back : sin pared trasera (se cierra con `tapa_trasera`). La pared trasera
                es la cara con Y positivo (+Y). Se deja un rebaje perimetral de
                `wall` mm para que la tapa trasera encaje al ras.
    """
    with BuildPart() as hb:
        Box(width, depth, height, align=(Align.CENTER, Align.CENTER, Align.MIN))
        # Bordes exteriores afilados (estilo monolito TARS). Si se quiere
        # aristas suaves, elevar FILLET_EDGE > 0.
        if FILLET_EDGE > 0:
            edges = hb.edges().filter_by(Axis.Z)
            if len(edges) > 0:
                try:
                    fillet(edges, radius=FILLET_EDGE)
                except Exception:
                    pass
    part = hb.part

    # Vaciado interior: se hace FUERA del BuildPart con resta booleana
    # explícita, porque Box(..., mode=SUBTRACT).locate() dentro del
    # contexto ignora la traslación y resta en el origen.
    inner_w = width - 2 * wall
    inner_d = depth - 2 * wall
    inner_h = height - wall - (0 if open_top else wall)
    inner = Box(
        inner_w, inner_d, inner_h,
        align=(Align.CENTER, Align.CENTER, Align.MIN),
    ).locate(Location((0, 0, wall)))
    part = part - inner

    # Apertura trasera (+Y) con labio perimetral para insertos M3.
    if open_back:
        REAR_MARGIN = 7.0
        cut_w = width - 2 * wall - 2 * REAR_MARGIN
        cut_h = height - wall - 2 * REAR_MARGIN
        cut_d = wall * 2 + 0.4  # cruza la pared trasera con holgura
        back_cutter = Box(
            cut_w, cut_d, cut_h,
            align=(Align.CENTER, Align.CENTER, Align.MIN),
        ).locate(Location((0, depth / 2 - wall, wall + REAR_MARGIN)))
        part = part - back_cutter

    return part


def front_rect_window(
    part: Part,
    z_center: float,
    w: float,
    h: float,
    depth: float,
    fillet_r: float = FILLET_INNER,
) -> Part:
    """Resta un rectángulo en la cara frontal (Y = -depth/2)."""
    cutter_d = WALL * 3  # suficiente para atravesar la pared
    with BuildPart() as c:
        Box(w, cutter_d, h, align=(Align.CENTER, Align.CENTER, Align.CENTER))
        if fillet_r > 0:
            fillet(c.edges().filter_by(Axis.Y), radius=fillet_r)
    cutter = c.part.locate(Location((0, -depth / 2, z_center)))
    return part - cutter


def front_circle_hole(
    part: Part,
    x: float,
    z: float,
    diameter: float,
    depth: float,
) -> Part:
    """Agujero circular en la cara frontal (eje Y)."""
    cutter = Cylinder(
        diameter / 2,
        WALL * 3,
        align=(Align.CENTER, Align.CENTER, Align.CENTER),
        rotation=(90, 0, 0),
    ).locate(Location((x, -depth / 2, z)))
    return part - cutter


def side_circle_hole(
    part: Part,
    side: str,  # "left" or "right"
    z: float,
    diameter: float,
    width: float,
) -> Part:
    """Agujero circular en la cara lateral (eje X)."""
    x = -width / 2 if side == "left" else width / 2
    cutter = Cylinder(
        diameter / 2,
        WALL * 3,
        align=(Align.CENTER, Align.CENTER, Align.CENTER),
        rotation=(0, 90, 0),
    ).locate(Location((x, 0, z)))
    return part - cutter


# ---------------------------------------------------------------------------
# DETALLES ESTÉTICOS: líneas de panel + texto grabado (estilo TARS de la peli)
# ---------------------------------------------------------------------------
def engrave_panel_line(
    part: Part,
    z: float,
    w: float,
    d: float,
    depth: float = 0.6,
    thickness: float = 1.2,
) -> Part:
    """Graba una línea horizontal fina en las 4 caras exteriores a altura z.

    No atraviesa la pieza; sólo resta `depth` mm en cada cara.
    """
    # Cara frontal (y = -d/2) y trasera (y = +d/2)
    fb = Box(w + 2.0, depth * 2, thickness,
             align=(Align.CENTER, Align.CENTER, Align.CENTER))
    part = part - fb.locate(Location((0, -d / 2, z)))
    part = part - fb.locate(Location((0, +d / 2, z)))
    # Caras laterales (x = ±w/2)
    lr = Box(depth * 2, d + 2.0, thickness,
             align=(Align.CENTER, Align.CENTER, Align.CENTER))
    part = part - lr.locate(Location((-w / 2, 0, z)))
    part = part - lr.locate(Location((+w / 2, 0, z)))
    return part


def engrave_panel_lines_modular(part: Part, w: float, d: float, units: int = 9) -> Part:
    """Graba una línea a cada múltiplo de UNIT (39 mm) excepto en z=0 y z=top."""
    for i in range(1, units):
        part = engrave_panel_line(part, i * UNIT, w, d)
    return part


def engrave_vertical_slats(
    part: Part,
    w: float,
    d: float,
    height: float,
    pitch: float = 8.0,
    line_thickness: float = 0.8,
    depth: float = 0.6,
    z_margin: float = 4.0,
    faces: tuple[str, ...] = ("front", "back", "left", "right"),
) -> Part:
    """Ranuras VERTICALES paralelas — el patrón principal del TARS de la peli.

    Simula el apilamiento de listones verticales que recubre todo el cuerpo.
    Cada cara exterior queda dividida en bandas verticales por líneas finas
    grabadas desde z_margin hasta height-z_margin.
    """
    z_len = height - 2 * z_margin
    z_c = z_margin + z_len / 2
    # Cutter para las caras frontal/trasera (ranura vertical en eje Z)
    fb = Box(line_thickness, depth * 2, z_len,
             align=(Align.CENTER, Align.CENTER, Align.CENTER))
    # Cutter para las caras laterales
    lr = Box(depth * 2, line_thickness, z_len,
             align=(Align.CENTER, Align.CENTER, Align.CENTER))
    # --- Frontal/Trasera: ranuras a lo ancho (eje X) ---
    if "front" in faces or "back" in faces:
        n = int(w // pitch)
        if n > 1:
            step = w / n
            for i in range(1, n):
                x = -w / 2 + i * step
                if "front" in faces:
                    part = part - fb.locate(Location((x, -d / 2, z_c)))
                if "back" in faces:
                    part = part - fb.locate(Location((x, +d / 2, z_c)))
    # --- Laterales: ranuras a lo largo del fondo (eje Y) ---
    if "left" in faces or "right" in faces:
        n = int(d // pitch)
        if n > 1:
            step = d / n
            for i in range(1, n):
                y = -d / 2 + i * step
                if "left" in faces:
                    part = part - lr.locate(Location((-w / 2, y, z_c)))
                if "right" in faces:
                    part = part - lr.locate(Location((+w / 2, y, z_c)))
    return part


def engrave_hatch_panel(
    part: Part,
    x_center: float,
    z0: float,
    z1: float,
    panel_w: float,
    d: float,
    pitch: float = 1.2,
    line_thickness: float = 0.6,
    depth: float = 0.5,
) -> Part:
    """Panel rectangular de rayado horizontal denso en la cara frontal.

    Usado para simular las "rejillas" que flanquean las pantallas en TARS.
    """
    cutter = Box(panel_w, depth * 2, line_thickness,
                 align=(Align.CENTER, Align.CENTER, Align.CENTER))
    z = z0
    while z <= z1:
        part = part - cutter.locate(Location((x_center, -d / 2, z)))
        z += pitch
    return part


def engrave_front_text(
    part: Part,
    text: str,
    z: float,
    d: float,
    size: float = 10.0,
    depth: float = 0.6,
) -> Part:
    """Graba texto en la cara FRONTAL (y = -d/2) centrado en (x=0, z)."""
    with BuildSketch(Plane.XZ) as sk:
        with Locations((0, z)):
            Text(text, font_size=size, align=(Align.CENTER, Align.CENTER))
    # Extrude along +Y (plane normal). Rotate 180° around Z to mirror letters
    # para que se lean correctamente desde -Y (frente).
    carve = extrude(sk.sketch, amount=depth + 0.2)
    carve = carve.rotate(Axis.Z, 180)
    # Mover hacia la cara frontal: el sólido queda de y=[-d/2-0.1, -d/2+depth+0.1]
    carve = carve.moved(Location((0, -d / 2 + depth + 0.1, 0)))
    return part - carve


def _as_part_global(s):
    """Boolean ops can return a ShapeList/Compound. Return the largest solid as Part."""
    if isinstance(s, Part):
        return s
    try:
        items = list(s)
    except TypeError:
        items = [s]
    solids = []
    for it in items:
        try:
            solids.extend(it.solids())
        except Exception:
            pass
    if not solids:
        solids = items
    solids.sort(key=lambda x: x.volume if hasattr(x, "volume") else 0, reverse=True)
    return Part(solids[0].wrapped) if not isinstance(solids[0], Part) else solids[0]
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

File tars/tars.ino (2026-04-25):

// =============================================================
//  TARS  (Arduino IDE sketch)
//  XIAO ESP32-S3 Sense | Groq Whisper + Llama | Telegram out
// =============================================================
//
//  REQUISITOS EN ARDUINO IDE:
//    1. File -> Preferences -> Additional Board Manager URLs, añade:
//       https://raw.githubusercontent.com/espressif/arduino-esp32/gh-pages/package_esp32_index.json
//    2. Tools -> Board Manager -> instala "esp32 by Espressif" (>= 3.0.0)
//    3. Tools -> Board -> ESP32 Arduino -> "XIAO_ESP32S3"
//    4. Tools -> USB CDC On Boot: "Enabled"
//    5. Tools -> PSRAM: "OPI PSRAM"
//    6. Tools -> Partition Scheme: "Huge APP (3MB No OTA/1MB SPIFFS)"
//    7. Sketch -> Include Library -> Manage Libraries -> instala:
//         - ArduinoJson (by Benoit Blanchon)
//    8. Copia "config.h.example" -> "config.h" y rellena tus claves.
//    9. Upload.
//
//  Flow:
//    1. Boot -> WiFi connect -> init PDM mic
//    2. Wait for voice (simple amplitude VAD)
//    3. Record WAV until silence
//    4. Upload WAV -> Groq Whisper -> text
//    5. Send text -> Groq Llama (TARS persona) -> reply
//    6. Reply -> Telegram bot
//    7. Back to step 2
//
// =============================================================

#include <Arduino.h>
#include "config.h"
#include "wifi_manager.h"
#include "audio_recorder.h"
#include "groq_client.h"
#include "gemini_client.h"
#include "telegram_client.h"
#include "memory_client.h"
#include "vision_client.h"
#include "behavior_state.h"
#include "intent_client.h"
#include "actions.h"
#include "autonomy.h"
#include "brain_context.h"

static void banner() {
    Serial.println();
    Serial.println(F("=============================================="));
    Serial.println(F("   TARS"));
    Serial.println(F("   Interstellar-inspired sarcastic robot"));
    Serial.println(F("=============================================="));
    Serial.printf ("  Humor level: %d%%\n", TARS_HUMOR_LEVEL);
    Serial.printf ("  STT model  : %s\n", GROQ_STT_MODEL);
#if GEMINI_ENABLED
    Serial.printf ("  LLM model  : %s  (vision en vivo=%s)\n",
                   GEMINI_MODEL, GEMINI_ALWAYS_SEE ? "si" : "no");
#else
    Serial.printf ("  LLM model  : %s\n", GROQ_LLM_MODEL);
#endif
    Serial.println(F("==============================================="));
}

void setup() {
    Serial.begin(115200);
    delay(1500);
    banner();

    if (!psramFound()) {
        Serial.println(F("[FATAL] PSRAM not detected. Tools -> PSRAM: OPI PSRAM"));
        while (true) delay(1000);
    }

    if (!wifi_mgr::connect()) {
        Serial.println(F("[FATAL] WiFi failed. Check config.h."));
        while (true) delay(1000);
    }

    if (!audio::begin()) {
        Serial.println(F("[FATAL] Audio init failed."));
        while (true) delay(1000);
    }

    // Camera is optional; if it fails we just log and continue without vision.
    if (!vision::begin()) {
        Serial.println(F("[WARN] Camera init failed; vision disabled."));
    }

    // Objetivos iniciales del robot. El LLM los ve cuando responde y los
    // usa para decidir a que prestar atencion. Puedes a\u00f1adir/quitar en caliente.
    brain::addGoal("conocer mejor a tu humano observando como trabaja");
    brain::addGoal("fijarte en objetos nuevos que no hayas registrado antes");
    brain::addGoal("no repetir el mismo comentario dos veces");
    brain::logMental("arranque del sistema");

    Serial.println(F("TARS online. Speak to me. Or don't. I'm a robot."));
}

// ---------- helpers ----------

static bool containsWakeWord(const String& low) {
#if !REQUIRE_WAKE_WORD
    return true;
#endif
    String words = WAKE_WORDS;
    words.toLowerCase();
    int start = 0;
    while (start < (int)words.length()) {
        int comma = words.indexOf(',', start);
        if (comma < 0) comma = words.length();
        String w = words.substring(start, comma);
        w.trim();
        if (w.length() > 0 && low.indexOf(w) >= 0) return true;
        start = comma + 1;
    }
    return false;
}

static bool isHallucination(const String& low) {
    static const char* H[] = {
        "thank you", "thanks for watching", "thanks", "you",
        "gracias", "subtitles by", "bye", ".", "..", "...",
        "amara.org", "transcription by", "music"
    };
    for (auto h : H) {
        if (low == h || low == String(h) + ".") return true;
    }
    return false;
}

// Apply intent: change state, run physical stub, return optional spoken reply.
static String applyIntent(intent::Kind k) {
    using namespace intent;
    switch (k) {
        case COME:    actions::approachUser(); behavior::set(behavior::COME,   "intent COME"); break;
        case STOP:    actions::halt();         behavior::set(behavior::IDLE,   "intent STOP"); break;
        case REST:    actions::sleep();        behavior::set(behavior::REST,   "intent REST"); break;
        case PLAY:    actions::playMode();     behavior::set(behavior::PLAY,   "intent PLAY"); break;
        case EXPLORE: actions::wander();       behavior::set(behavior::EXPLORE,"intent EXPLORE"); break;
        case LOOK:    actions::lookHere();     /* state unchanged */ break;
        case CHAT:    /* nothing */ break;
    }
    return "";
}
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

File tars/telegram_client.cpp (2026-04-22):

#include "telegram_client.h"
#include "config.h"

#include <WiFiClientSecure.h>
#include <HTTPClient.h>
#include <ArduinoJson.h>

namespace tg {

bool send(const String& text) {
    if (!SEND_MESSAGE_TELEGRAM) {
        Serial.printf("[TG] Disabled in config; would have sent: %s\n", text.c_str());
        return true;
    }

    WiFiClientSecure client;
    client.setInsecure();
    client.setHandshakeTimeout(30);

    HTTPClient http;
    String url = "https://api.telegram.org/bot";
    url += TELEGRAM_BOT_TOKEN;
    url += "/sendMessage";

    if (!http.begin(client, url)) {
        Serial.println("[TG] http.begin failed");
        return false;
    }
    http.addHeader("Content-Type", "application/json");
    http.setTimeout(HTTP_TIMEOUT_MS);

    JsonDocument doc;
    doc["chat_id"] = TELEGRAM_CHAT_ID;
    doc["text"]    = text;

    String payload;
    serializeJson(doc, payload);

    int code = http.POST(payload);
    String body = http.getString();
    http.end();

    if (code == 200) {
        Serial.println("[TG] Telegram sent OK");
        return true;
    }
    Serial.printf("[TG] HTTP %d: %s\n", code, body.c_str());
    return false;
}

} // namespace tg

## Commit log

2026-04-24 feat: Add detailed mechanical design documentation for TARS Phase 3, including components, dimensions, and assembly instructions
2026-04-24 Update README.md and build documentation for TARS Robot
    - Revised hardware components in README.md to reflect current specifications, including changes to sensors, battery, and display.
    - Updated phase descriptions and total hardware costs in README.md.
    - Added a legacy warning and clarification in Spanish and French build documents to indicate discrepancies with the current canonical design.
    - Included links to updated phase documentation for accurate reference.
2026-04-25 feat: Integrate Gemini 2.0 Flash for multimodal interaction
    - Added Gemini API key and model configuration to config.h.example.
    - Implemented gemini_client for handling requests to Gemini API with support for image capture.
    - Updated tars.ino to utilize Gemini for responses, enabling real-time vision integration.
    - Enhanced vision_client to capture JPEG images in base64 format for Gemini requests.
    - Added new test file for future testing of Gemini integration.
    [PREVIEW_tars_robot.3mf, PREVIEW_tars_robot.stl, bloque_central.3mf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]
